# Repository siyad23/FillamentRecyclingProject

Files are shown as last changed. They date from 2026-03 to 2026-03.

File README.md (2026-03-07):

# Filament Recycling Project

A complete open-source plastic bottle-to-3D-printer-filament recycling machine, encompassing mechanical design, electrical design, and embedded firmware. The system heats, extrudes, and spools recycled plastic into usable 3D printing filament using a custom-built machine controlled by an ESP32-C6 microcontroller.

---

## Gallery

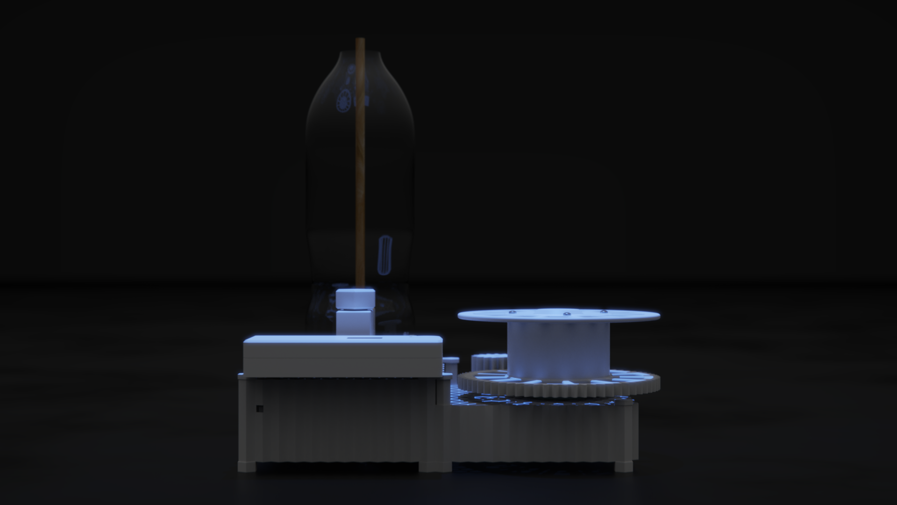
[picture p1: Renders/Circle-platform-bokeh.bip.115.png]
Render 1

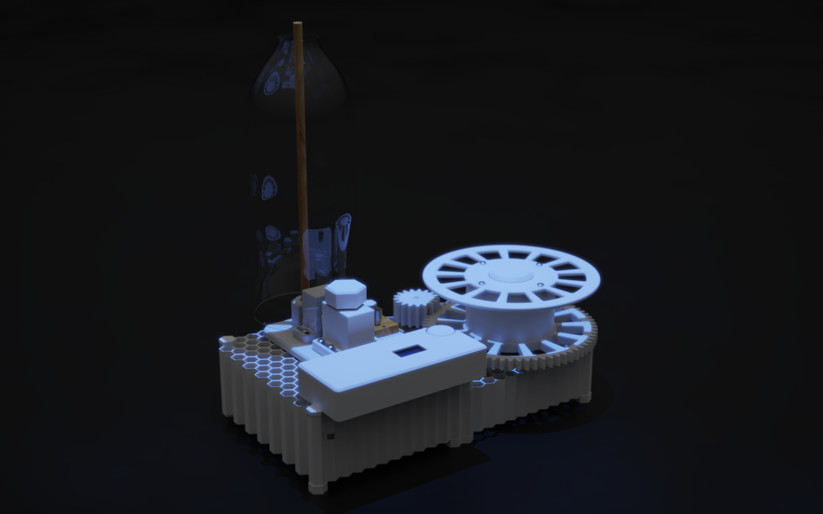
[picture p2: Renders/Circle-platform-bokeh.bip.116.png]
Render 2

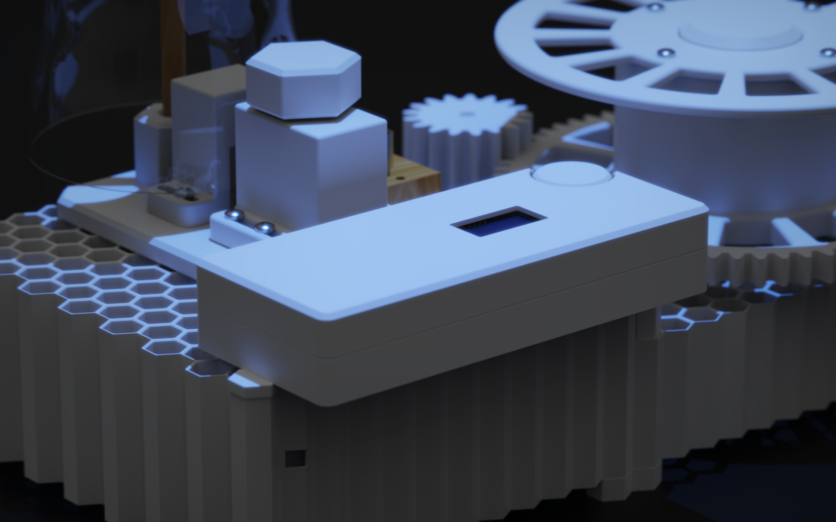
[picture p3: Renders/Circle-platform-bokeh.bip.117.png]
Render 3

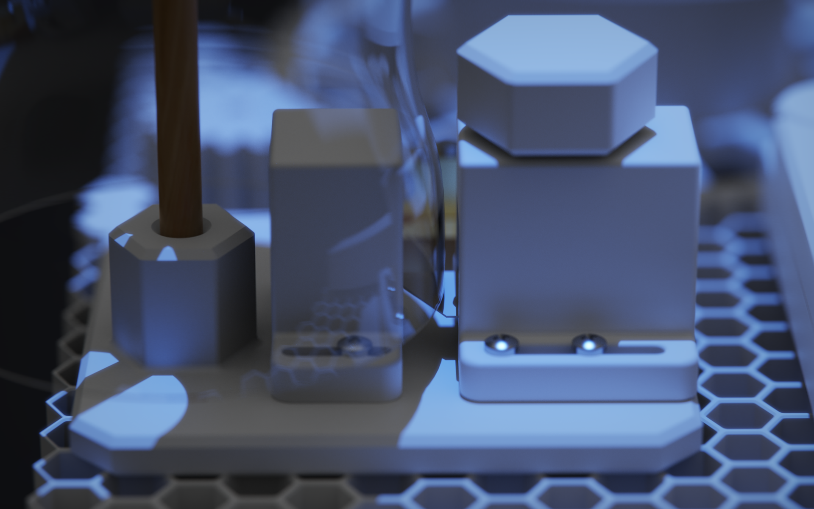
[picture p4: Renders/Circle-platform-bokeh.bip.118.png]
Render 4

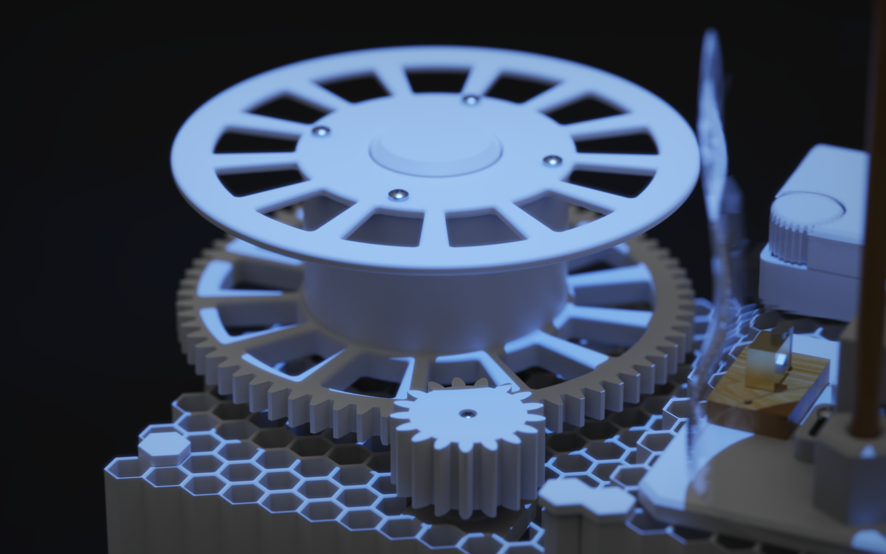
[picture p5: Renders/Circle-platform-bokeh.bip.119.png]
Render 5

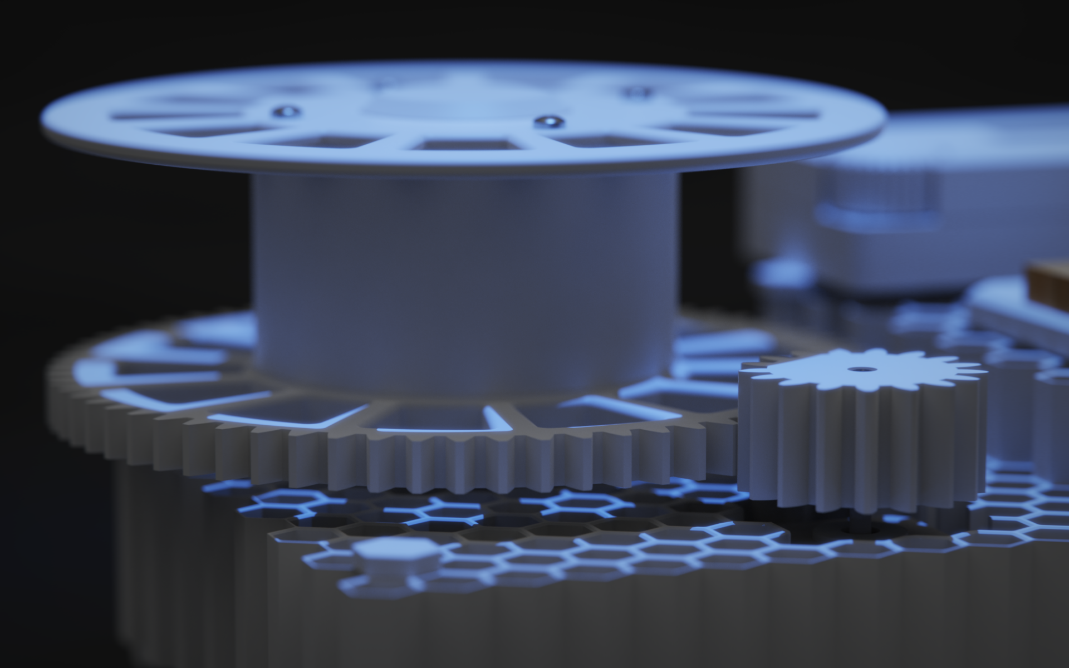
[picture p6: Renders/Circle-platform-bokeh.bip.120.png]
Render 6

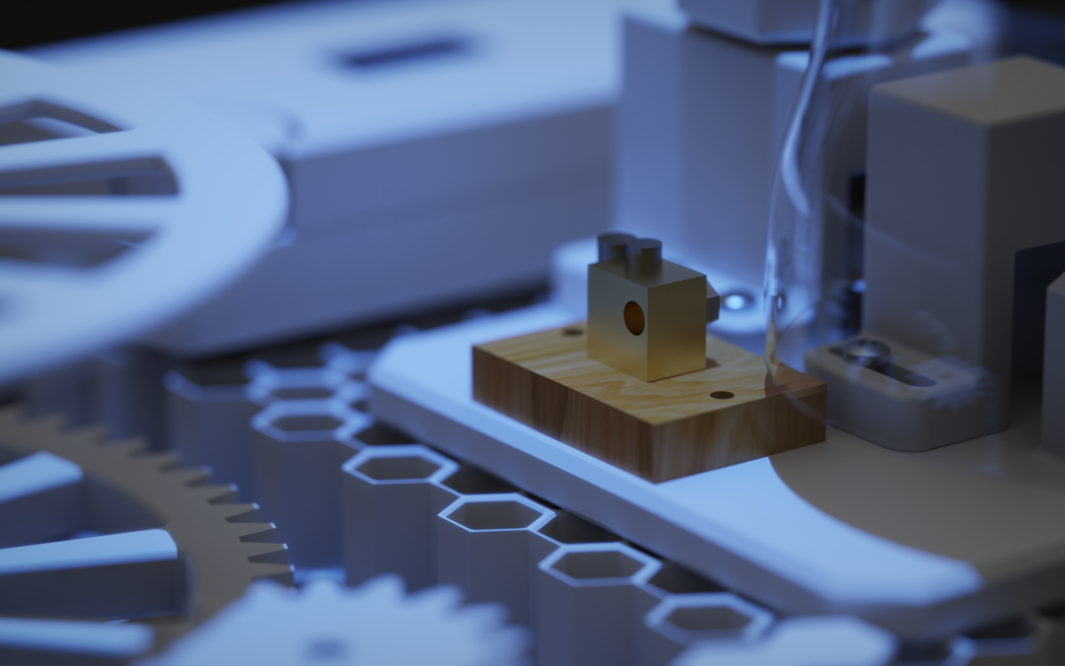
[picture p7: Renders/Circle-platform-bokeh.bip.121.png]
Render 7


---

## Table of Contents

- [Overview](#overview)
- [Features](#features)
- [Project Structure](#project-structure)
- [Hardware Components](#hardware-components)
- [Firmware](#firmware)
  - [Menu System](#menu-system)
  - [Pin Configuration](#pin-configuration)
  - [PID Temperature Control](#pid-temperature-control)
- [Mechanical Design](#mechanical-design)
  - [Cutting Mechanism](#cutting-mechanism)
  - [Gear Train](#gear-train)
  - [Spool Assembly](#spool-assembly)
  - [Electrical Enclosure](#electrical-enclosure)
  - [Production Phases](#production-phases)
- [Build & Flash](#build--flash)
- [Usage](#usage)
- [License](#license)

---

## Overview

This project converts plastic bottles into 3D printer filament through a process of cutting, heating, extruding, and spooling. The machine is driven by a stepper motor controlled through a TB6600 driver, with a heated extruder regulated by a PID controller reading a MAX6675 thermocouple. All user interaction is handled through a rotary encoder and a 128×64 SH1106 OLED display.

## Features

- **PID-controlled heated extruder** with closed-loop (PID) and open-loop (fixed power) modes
- **Stepper motor control** with configurable speed (0–100%) and microstepping (1, 2, 4, 8, 16, 32)
- **MAX6675 thermocouple** for real-time temperature monitoring (up to 250 °C)
- **128×64 SH1106 OLED display** with animated splash screen, scrollable menus, progress bars, and icons
- **Rotary encoder navigation** with acceleration-aware input for fast/slow value adjustment
- **Non-Volatile Storage (NVS)** — all settings (temperature, speed, PID gains, pin assignments) persist across power cycles with flash-wear-optimized writes
- **Fully configurable GPIO pins** — reassign stepper, heater, and thermocouple pins from the on-device menu
- **Time-proportional heater control** (1 Hz software PWM) for proportional power output without hardware PWM
- **4-phase 3D-printable mechanical design** with full SolidWorks source files

---

## Project Structure

```
fillamentRecyclingProject/
├── README.md
├── ElectricalDesign/                  # Electrical schematics & PCB designs
├── fillamentRecyclingProjectCode/     # ESP32-C6 firmware (ESP-IDF + PlatformIO)
│   ├── CMakeLists.txt
│   ├── platformio.ini                 # PlatformIO config (ESP32-C6-DevKitM-1)
│   ├── sdkconfig.esp32-c6-devkitm-1
│   ├── include/
│   ├── lib/
│   ├── src/
│   │   ├── main.c                     # Application entry point, menu system, control loop
│   │   ├── sh1106.c / sh1106.h        # SH1106 OLED display driver (I2C)
│   │   └── AiEsp32RotaryEncoder.c/.h  # Rotary encoder driver (ESP-IDF port)
│   └── test/
└── MechanicalDesign/                  # SolidWorks CAD files
    ├── MainAssembly.SLDASM            # Top-level assembly
    ├── baseAssembly.SLDASM            # Base frame assembly
    ├── spoolAssembly.SLDASM           # Spool winding assembly
    ├── electricalBoxAssembly.SLDASM   # Electronics enclosure assembly
    ├── CuttingMechanism/              # Bottle cutting sub-assembly
    ├── ProductionDocuments/           # 3D-print-ready STLs & build guides (Phase 1–4)
    └── ReferenceFiles/                # Vendor CAD models & datasheets
```

---

## Hardware Components

| Component | Description |
|---|---|
| **ESP32-C6-DevKitM-1** | Main microcontroller (RISC-V, Wi-Fi 6, BLE 5) |
| **SH1106 128×64 OLED** | I2C display (address 0x3C) for user interface |
| **HW-040 Rotary Encoder** | Navigation input with push-button |
| **TB6600 Stepper Driver** | Drives the extruder/spool stepper motor |
| **MAX6675 + K-Type Thermocouple** | Temperature sensing for the hotend (bit-banged SPI) |
| **Heater Cartridge** | Hotend heating element (time-proportional control) |
| **SMPS Power Supply** | Main power source |
| **BTS7960 Motor Driver** | Reference motor driver (in reference files) |
| **Bearings** | SKF 6008 (25×47×16 mm) and 63005-2RS1 |
| **Flexible Coupling (5×5 mm)** | Motor-to-shaft coupler |
| **Spur Gears** | 15T, 17T, and 67T gear train for speed reduction |

---

## Firmware

The firmware is written in **C** using the **ESP-IDF** framework and managed via **PlatformIO**.

### Menu System

The OLED display presents a hierarchical menu navigated entirely via the rotary encoder:

```
SPLASH (animated loading screen, 2 seconds)
└── MAIN MENU
    ├── Start/View Process  → RUN screen (live temp, motor speed, elapsed time, progress bar)
    │                         └── Confirm Stop dialog
    ├── Temperature         → Slider (30–250 °C, speed-adaptive steps: 1/5/10/20)
    ├── Motor Speed         → Slider (0–100%)
    ├── Microstep           → Selector (1/1, 1/2, 1/4, 1/8, 1/16, 1/32)
    ├── Hotend Mode         → Closed Loop (PID) / Open Loop (fixed %)
    │   └── Heater Power    → Slider (0–100%, open-loop only)
    ├── PID Settings
    │   ├── Kp (0.0–10.0)
    │   ├── Ki (0.0–5.0)
    │   └── Kd (0.0–10.0)
    └── Pin Settings        → Reassign all 7 GPIO pins (0–21)
```

### Pin Configuration

Default GPIO assignments (all configurable via the on-device menu):

| Function | Default GPIO |
|---|---|
| I2C SCL | 20 |
| I2C SDA | 19 |
| Encoder A | 15 |
| Encoder B | 18 |
| Encoder Button | 14 |
| Stepper STEP | 4 |
| Stepper DIR | 5 |
| Stepper ENABLE | 6 |
| Heater | 7 |
| MAX6675 CLK | 10 |
| MAX6675 CS | 11 |
| MAX6675 DO | 12 |

### PID Temperature Control

The closed-loop temperature controller implements:

- **Proportional, Integral, Derivative** control with configurable gains
- **Derivative-on-measurement** (avoids setpoint kick on temperature changes)
- **Anti-windup** clamping on the integral term (±100)
- **Time-proportional output** — a 1-second window where the heater is on for `(pid_output / 100) × 1000 ms`
- Temperature sampled every 250 ms from the MAX6675 (respecting the sensor's ~220 ms conversion time)

---

## Mechanical Design

All CAD files are in **SolidWorks** format (.SLDPRT for parts, .SLDASM for assemblies).

### Cutting Mechanism

Located in `MechanicalDesign/CuttingMechanism/`:

- **Blade & Blade Holder** — upper and lower holders secure the cutting blade
- **Blade Housing** — enclosed cutting chamber
- **Bottle Base & Size Adjustor** — accommodates different bottle diameters
- **Height Adjustment Screws** — fine-tune blade position
- **Metal Rod** — structural support for the cutting assembly

### Gear Train

Three spur gears provide mechanical advantage for the extrusion process:

- **15T Spur Gear** — driver gear
- **17T Spur Gear** — intermediate gear
- **67T Spur Gear** — driven gear (high torque output)

### Spool Assembly

- **Filament Spool** (2 variants) — collects the finished filament
- **Spool Plate** — mounting plate for the spool
- **Coupler** — connects motor shaft to spool mechanism
- **Knob** — manual spool adjustment

### Electrical Enclosure

- **Electrical Box** + **Lid** — houses the ESP32, motor driver, and power supply
- **Mount Stand** — secures the enclosure to the base

### Base Frame

- **Base** (standard and hex variants) — machine foundation
- **Base Feet & Double Joiner Feet** — anti-vibration feet
- **Base Joiner** — connects base sections
- **Bearing Mount** — supports rotating shafts (SKF 6008 / 63005-2RS1)
- **Fasteners** (1× and 4× variants) — structural fasteners

### Production Phases

The build is organized into 4 print phases under `MechanicalDesign/ProductionDocuments/`:

| Phase | Parts (STL files) | Description |
|---|---|---|
| **Phase 1** | Base, Blade Holder, Blade Housing, Height Adjustment Screws, Size Adjustor | Cutting mechanism & base plate |
| **Phase 2** | Base (×3), Base Feet (×2), Base Joiner, Double Joiner Feet, Fasteners (×2) | Frame structure & assembly |
| **Phase 3** | Bearing Mount, Electrical Box & Lid, Fasteners, Knob, Mount Stand, Spool, Spool Plate, Spur Gear | Enclosure, spool, and drive train |
| **Phase 4** | Blade Holder, Spur Gear | Final assembly parts |

Each phase includes a PDF/DOCX build guide.

---

## Build & Flash

### Prerequisites

- [PlatformIO](https://platformio.org/) (VS Code extension or CLI)
- ESP32-C6-DevKitM-1 board
- USB-C cable

### Steps

```bash
# Clone the repository
git clone <repository-url>
cd fillamentRecyclingProject/fillamentRecyclingProjectCode

# Build the firmware
pio run -e esp32-c6-devkitm-1

# Flash to the board
pio run -e esp32-c6-devkitm-1 --target upload

# Monitor serial output
pio device monitor
```

---

## Usage

1. **Power on** — the OLED displays an animated splash screen with a recycling logo.
2. **Navigate** — rotate the encoder to scroll through menu items; click to select.
3. **Configure** — set temperature (30–250 °C), motor speed, microstepping, hotend mode, and PID gains.
4. **Start** — select "Start Process" to enable the heater and motor. The run screen shows live temperature, target, heater power %, motor speed, elapsed time, and a temperature progress bar.
5. **Stop** — select "STOP" on the run screen or long-press the encoder (1 second) from the main menu. A confirmation dialog prevents accidental shutdowns.
6. **Settings persist** — all parameters are saved to flash automatically and restored on next boot.

---

## License

This project is licensed under the MIT License - see the [LICENSE](LICENSE) file for details.

Copyright (c) 2026 Rahat Khan Siyad

The rotary encoder library is based on [ai-esp32-rotary-encoder](https://github.com/igorantolic/ai-esp32-rotary-encoder) by Igor Antolic (MIT License).

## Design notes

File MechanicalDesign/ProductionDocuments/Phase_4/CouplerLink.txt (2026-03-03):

https://store.roboticsbd.com/robotics-parts/2260-5mm-motor-shaft-coupling-brass-hex-18mm-length-robotics-bangladesh.html

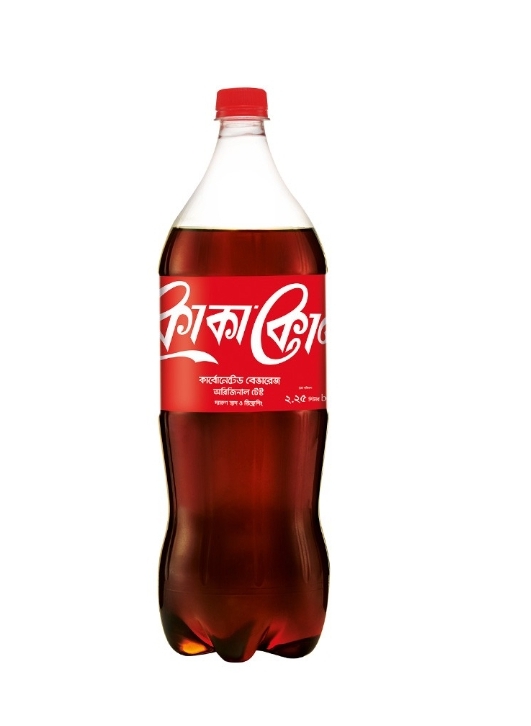
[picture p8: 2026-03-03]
MechanicalDesign/ReferenceFiles/YGOv7M2TLwKPeQucEshsfxZYIpocbmotxgK6eAaB.jpg

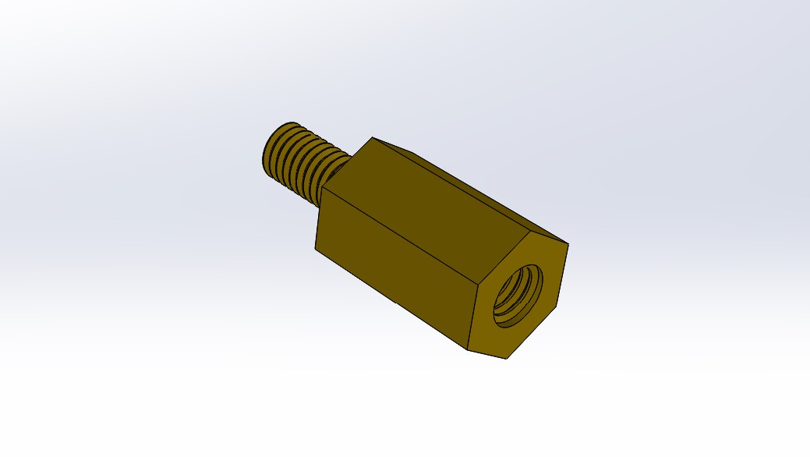
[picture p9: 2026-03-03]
MechanicalDesign/ReferenceFiles/m3-x10mm-spacer-1.snapshot.1/Spacer .jpg

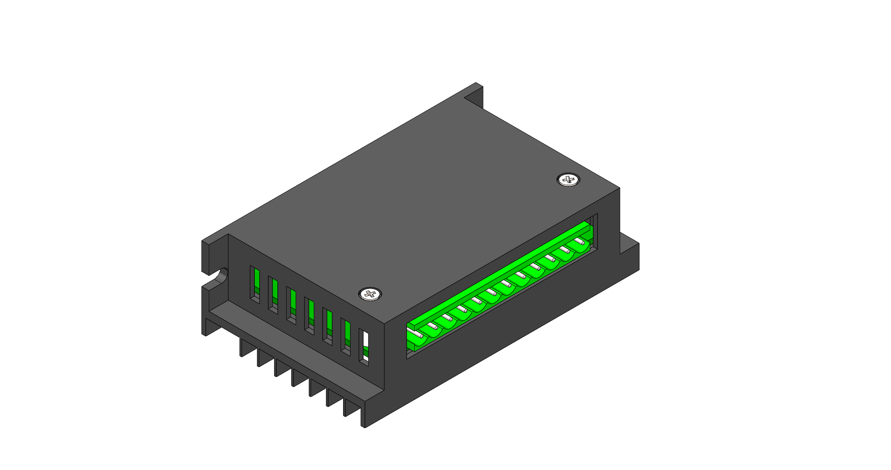
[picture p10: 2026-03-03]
MechanicalDesign/ReferenceFiles/TB6600_MotorDriver/MotordriverAssebly.PNG

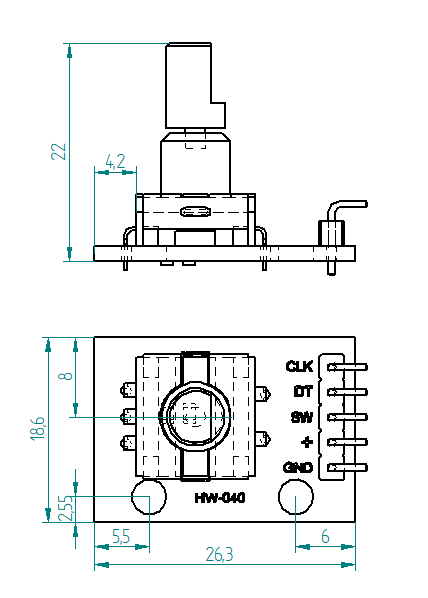
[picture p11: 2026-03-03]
MechanicalDesign/ReferenceFiles/hw-040-rotary-encoder-for-arduino-1.snapshot.3/HW-040 Module dimensions.png

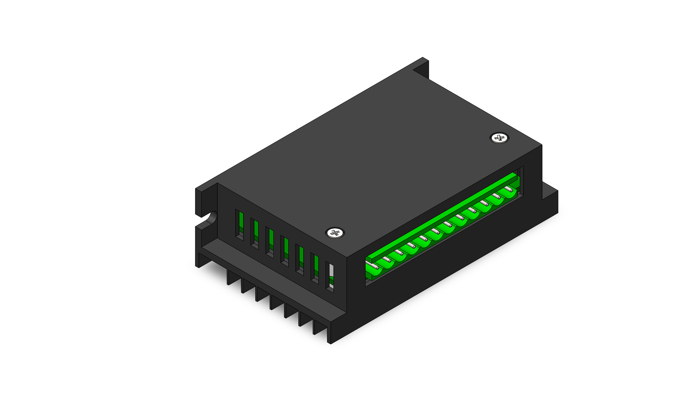
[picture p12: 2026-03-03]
MechanicalDesign/ReferenceFiles/TB6600_MotorDriver/Assem1.JPG

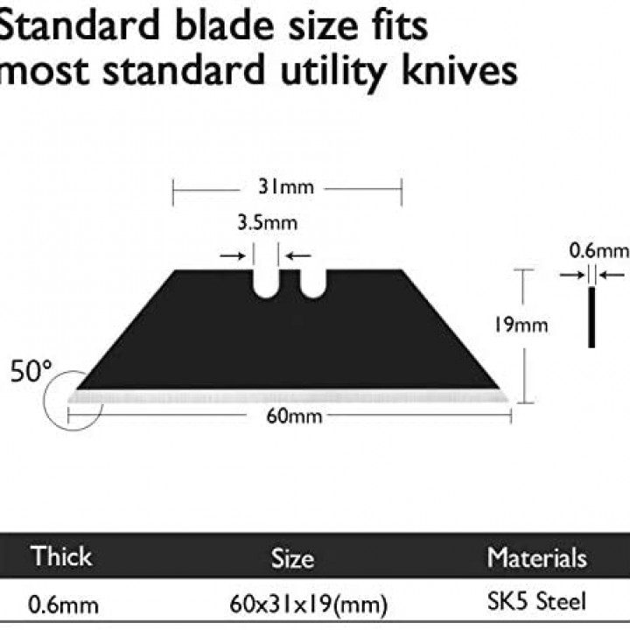
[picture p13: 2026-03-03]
MechanicalDesign/ReferenceFiles/bladeDimensions.jpg

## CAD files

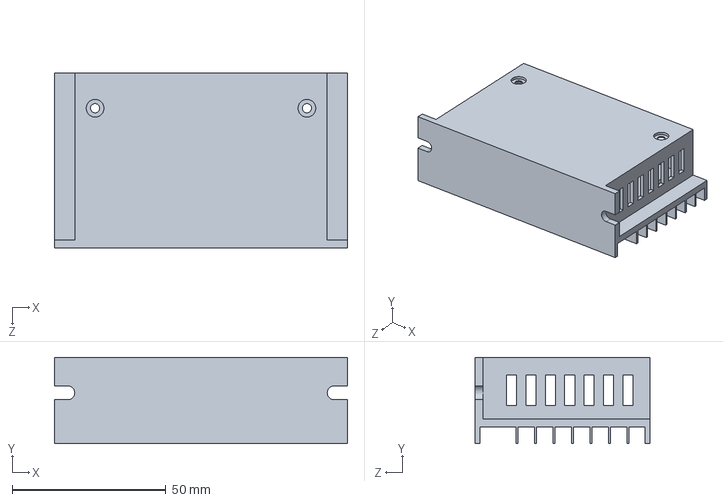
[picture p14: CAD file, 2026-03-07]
MechanicalDesign/ReferenceFiles/TB6600_MotorDriver/mainBody.SLDPRT
95.3 x 28.1 x 56.8 mm

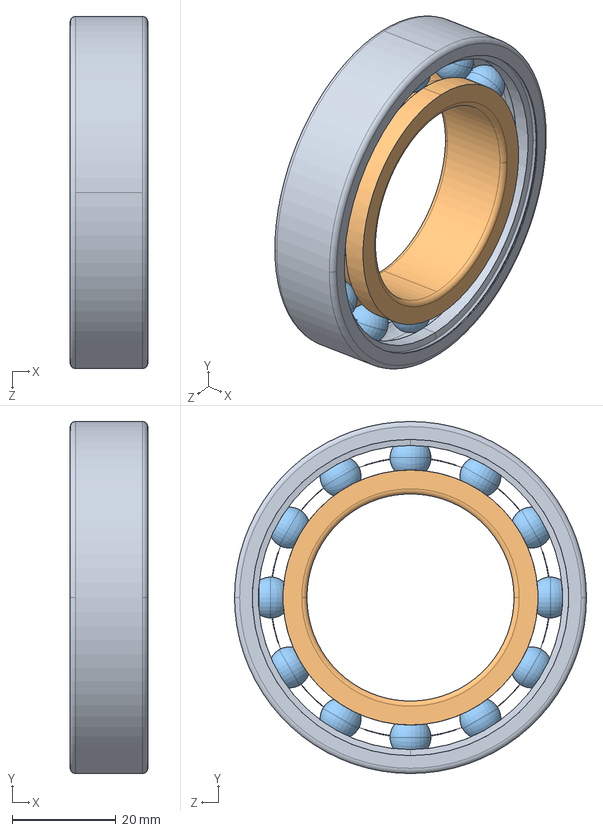
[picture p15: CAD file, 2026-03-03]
MechanicalDesign/ReferenceFiles/175567098-7-6008/6008.SLDASM
15.0 x 68.0 x 68.0 mm

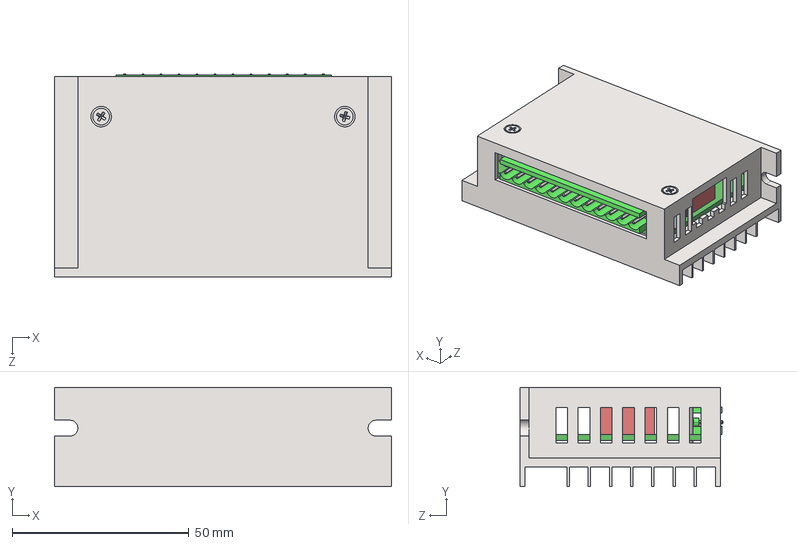
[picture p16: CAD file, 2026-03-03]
MechanicalDesign/ReferenceFiles/TB6600_MotorDriver/Assembly.STEP
95.3 x 28.1 x 57.5 mm
PCB
MaleConnector
switch
mainBody
bottomSpacer x 2
topSpacer x 2
flat head screw_am_B18.6.7M - M2.5 x 0.45 x 20 Type I Cross Recessed FHMS --20C x 2

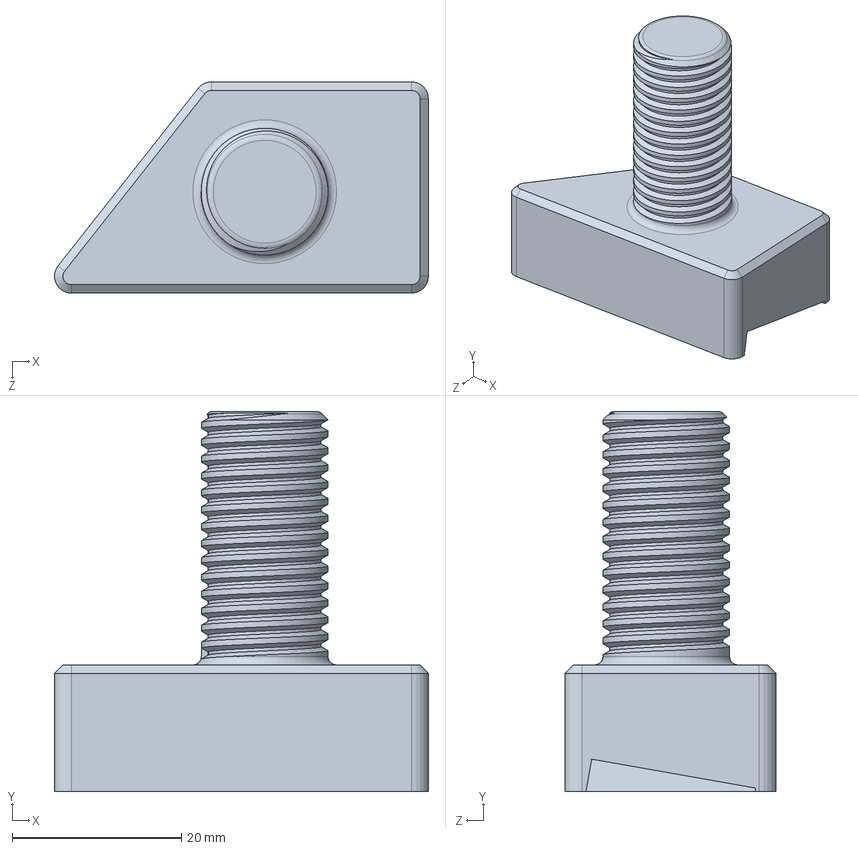
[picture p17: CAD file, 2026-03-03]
MechanicalDesign/CuttingMechanism/bladeHolder.SLDPRT
44.2 x 45.0 x 25.0 mm

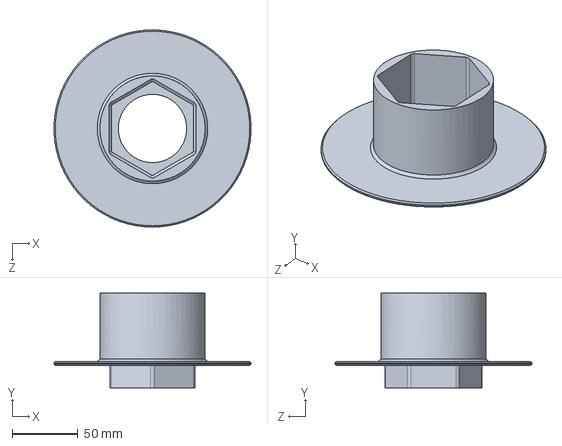
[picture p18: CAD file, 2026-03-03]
MechanicalDesign/fillametSpool2.SLDPRT
149.9 x 72.0 x 150.0 mm

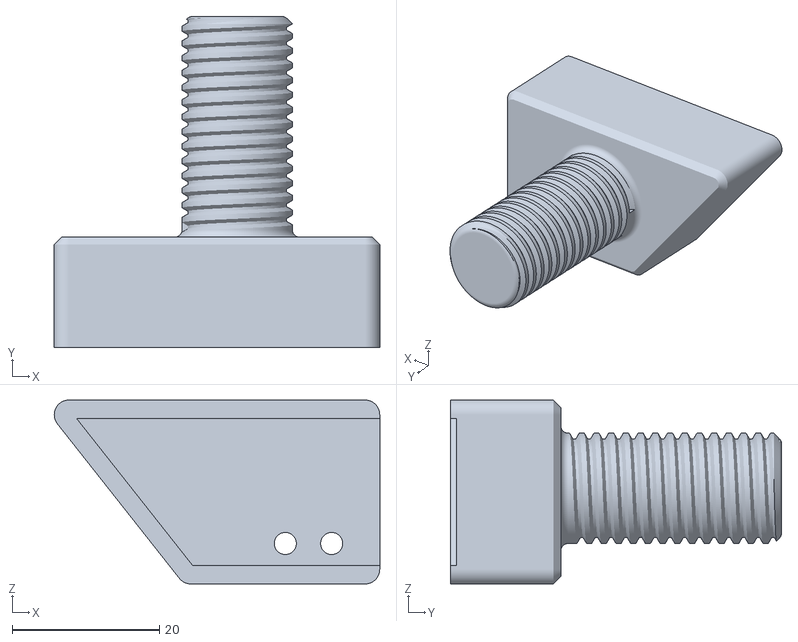
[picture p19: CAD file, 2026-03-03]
MechanicalDesign/ProductionDocuments/Phase_1/bladeHolder.STL
44.3 x 45.0 x 25.0

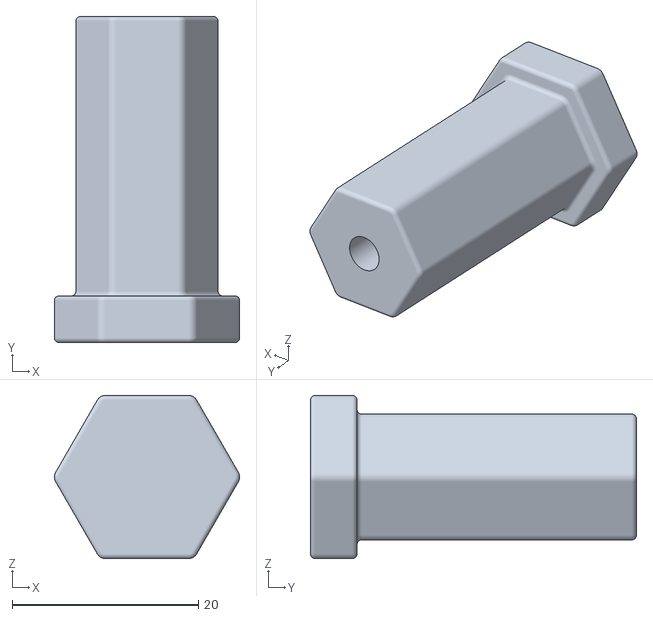
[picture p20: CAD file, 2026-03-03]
MechanicalDesign/ProductionDocuments/Phase_2/baseFeet_2.STL
19.9 x 35.0 x 17.5

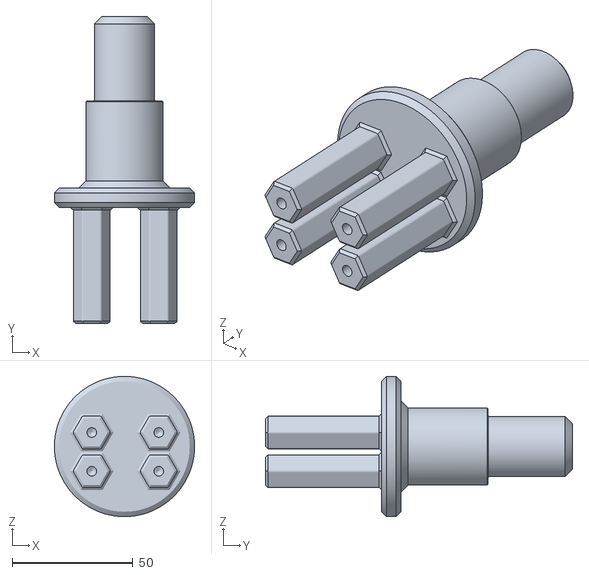
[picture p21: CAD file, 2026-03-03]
MechanicalDesign/ProductionDocuments/Phase_3/mountStand.STL
58.0 x 127.0 x 58.0

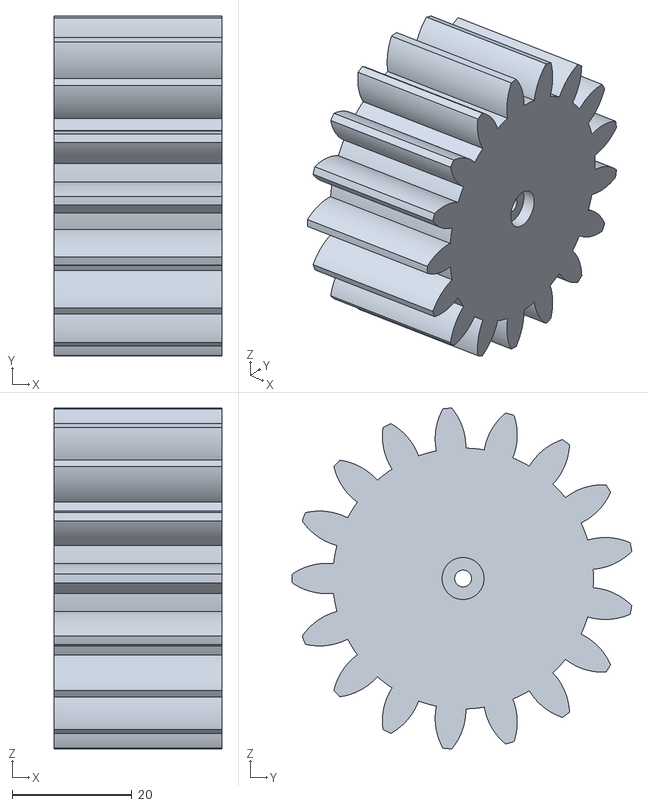
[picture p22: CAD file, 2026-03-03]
MechanicalDesign/ProductionDocuments/Phase_4/SpurGear.STL
28.0 x 56.6 x 56.9

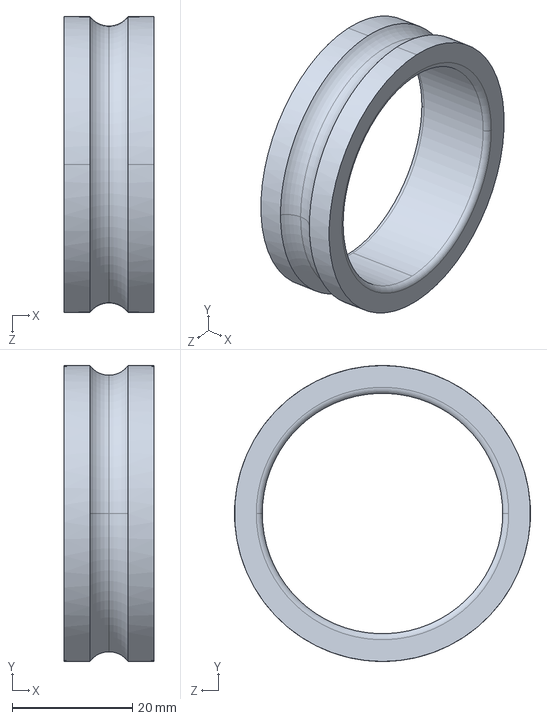
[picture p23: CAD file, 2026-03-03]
MechanicalDesign/ReferenceFiles/175567098-7-6008/6008_02.SLDPRT
15.0 x 49.2 x 49.2 mm

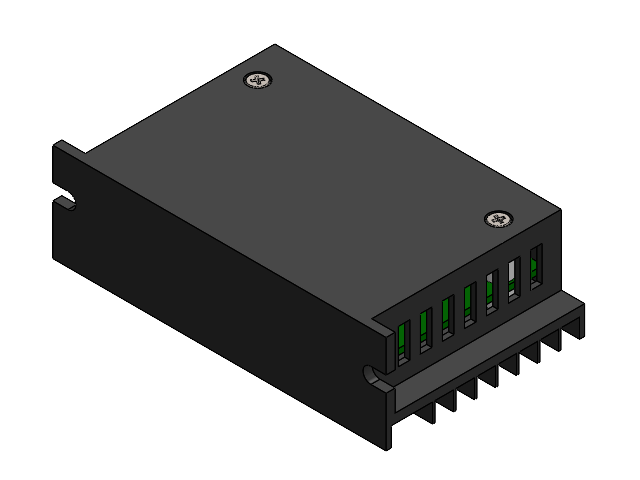
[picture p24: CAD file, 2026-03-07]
MechanicalDesign/ReferenceFiles/TB6600_MotorDriver/MotordriverAssebly.SLDASM
PCB
MaleConnector
switch
mainBody
bottomSpacer x 2
topSpacer x 2
flat head screw_am x 2

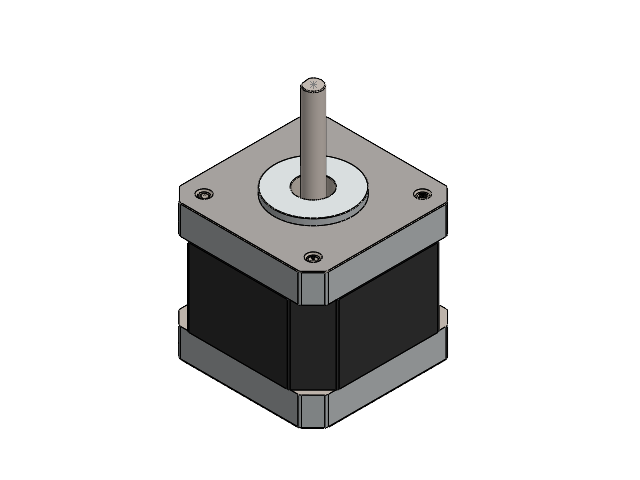
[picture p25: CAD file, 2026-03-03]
MechanicalDesign/ReferenceFiles/MotorDesign/motorAssembly.SLDASM
bottomPlate
midBody
shaft
topPlate
jstConnector

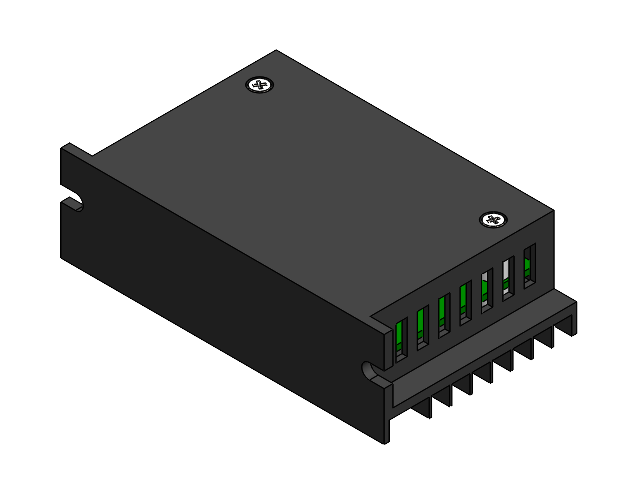
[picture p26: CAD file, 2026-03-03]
MechanicalDesign/ReferenceFiles/TB6600_MotorDriver/Assem1.SLDASM
PCB
MaleConnector
switch
mainBody
bottomSpacer x 2
topSpacer x 2
flat head screw_am x 2

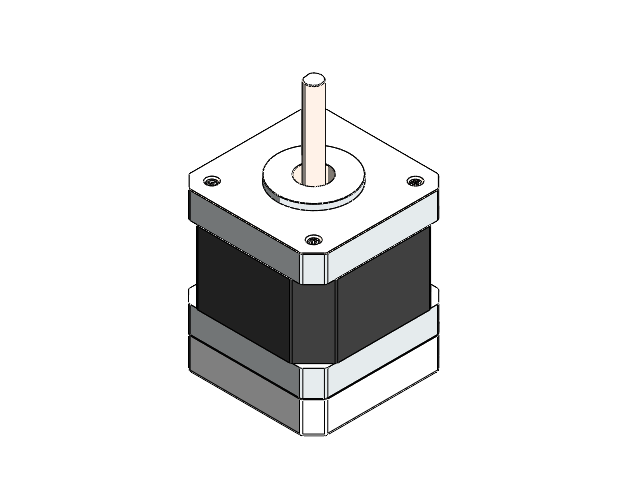
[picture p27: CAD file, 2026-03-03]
MechanicalDesign/ReferenceFiles/MotorDesign/motorWithEncoder.SLDASM
bottomPlate
midBody
shaft
topPlate
jstConnector
magneticEncoderEnclosure
AS5600

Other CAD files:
MechanicalDesign/spoolAssembly.SLDASM
MechanicalDesign/ReferenceFiles/TB6600_MotorDriver/MotordriverAsseblys.SLDASM
MechanicalDesign/ReferenceFiles/TB6600_MotorDriver/mainBodys.SLDPRT
MechanicalDesign/electricalBoxAssembly.SLDASM
MechanicalDesign/15xSpurGear.SLDPRT
MechanicalDesign/17xSpurGear.SLDPRT
MechanicalDesign/67xSpurGear.SLDPRT
MechanicalDesign/Base.SLDPRT
MechanicalDesign/Coupler.SLDPRT
MechanicalDesign/CuttingMechanism/Part3.SLDPRT
MechanicalDesign/CuttingMechanism/blade.SLDPRT
MechanicalDesign/CuttingMechanism/bladeHolder_Lower.SLDPRT
MechanicalDesign/CuttingMechanism/bladeHousing.SLDPRT
MechanicalDesign/CuttingMechanism/bottle.SLDPRT
MechanicalDesign/CuttingMechanism/bottleBase.SLDPRT
MechanicalDesign/CuttingMechanism/bottleSizeAdjustor.SLDPRT
MechanicalDesign/CuttingMechanism/heightAdjustmentScrews.SLDPRT
MechanicalDesign/CuttingMechanism/metalRod.SLDPRT
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

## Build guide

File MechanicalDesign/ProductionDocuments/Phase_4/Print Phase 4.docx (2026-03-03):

# Print Phase – 4

All files are in this drive folder: Phase_4_Files (https://drive.google.com/drive/folders/1dxNh4X9nQZPrIZS_Qf4CVorg8Dkla8L0?usp=sharing)

***The print orientation is shown in pictures. If the parts fail to print in that orientation, you may change the orientation.

# 1. Base Type 1

file Name: bladeHolder.STL

Link: bladeHolder (https://drive.google.com/file/d/19umH6-jGS0w7vAI4DKsR5vvIBFBa8NWH/view?usp=drive_link)

Infill: 20%.

Wall Loops: 5

Color: White

Precision (Flowrate): High (Low)

Material: PETG

Quantity: 1

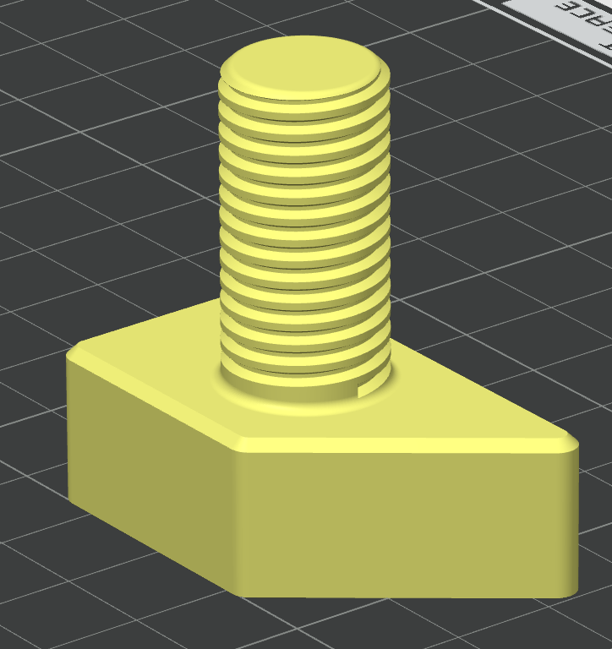
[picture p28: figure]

# 2. Base Type 2

file Name: spurGear.STL

Link: SpurGear (https://drive.google.com/file/d/1pW3XLnhzH5lOOCwImbOTlCXtp-f2U9rn/view?usp=drive_link)

Infill: 20%.

Wall Loops: 6

Color: White

Precision (Flowrate): High (Low)

Material: PETG

Quantity: 1

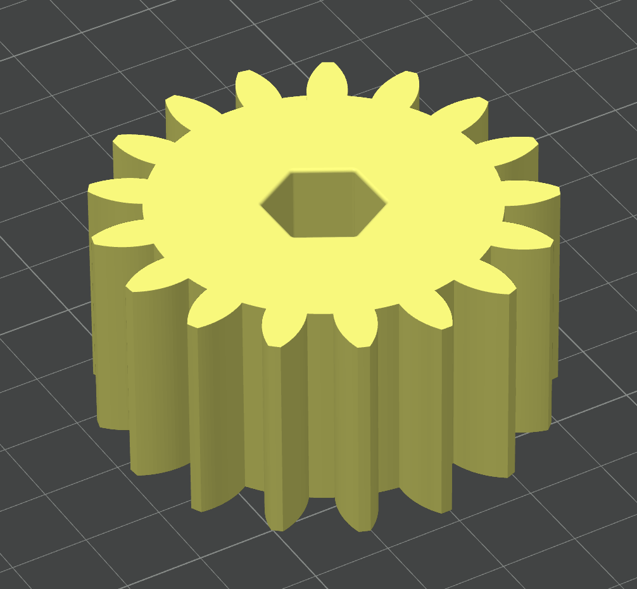
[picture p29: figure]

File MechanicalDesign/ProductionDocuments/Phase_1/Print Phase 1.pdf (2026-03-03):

## Print Phase – 1

All files are in this drive folder: Phase_1_Files (https://drive.google.com/drive/folders/1WSvoMfZPsJ0MehgL9uLIRmyDcuyFN0G7?usp=sharing)
***The print orientation is shown in pictures. If the parts fail to print in that orientation, you may change the orientation.

## 1. Base

file Name: Base.STL
Link: base.stl (https://drive.google.com/file/d/1UHYACKnU-G3ZPhq-Jozfw69xOXjVucC-/view?usp=drive_link)
Infill: 20%
Color: White
Precision (Flowrate): Medium (Medium) Material: PETG
Quantity: 1

## 2. Size Adjustor

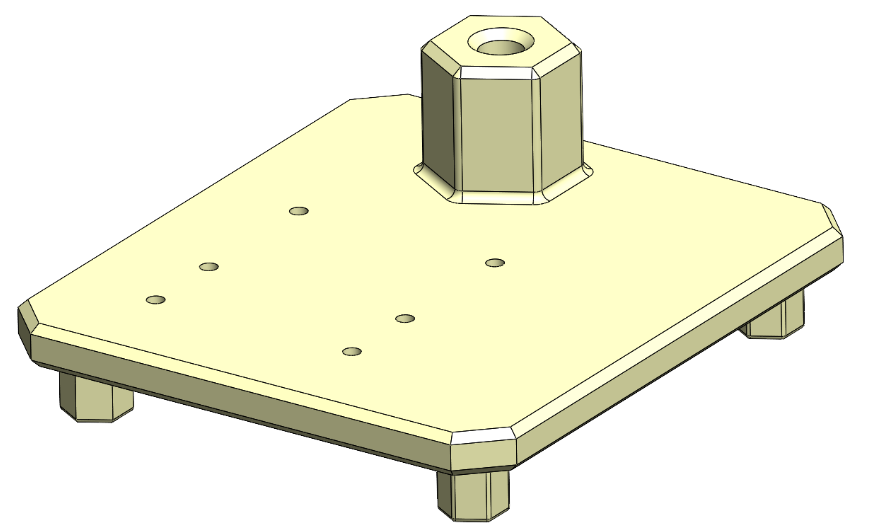
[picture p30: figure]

file Name: SizeAdjustor.STL Link: SizeAdjustor (https://drive.google.com/file/d/17B-TPPNcGwmfyJ7Izo8fIt5Hx-thai_7/view?usp=drive_link%20)
Infill: 20%
Color: White
Precision (Flowrate): Medium (Medium) Material: PETG
Quantity: 1

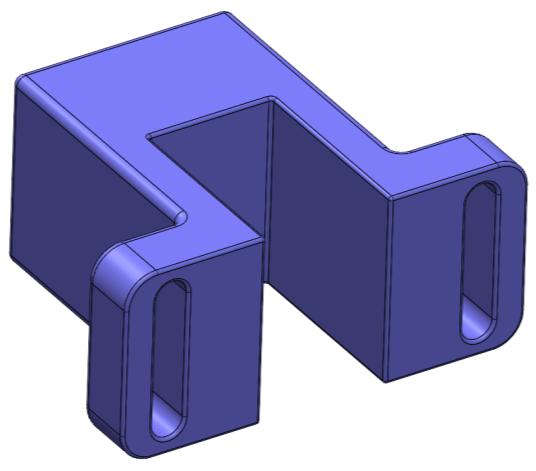
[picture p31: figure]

## 3. Blade Housing

file Name: bladeHousing.STL Link: bladeHousing (https://drive.google.com/file/d/1ppzdyYx5xnflyTPJfxlkGqCSifSpGc2D/view?usp=drive_link)
Infill: 50%
Color: White
Precision (Flowrate): High (Low) Material: PETG
Quantity: 1

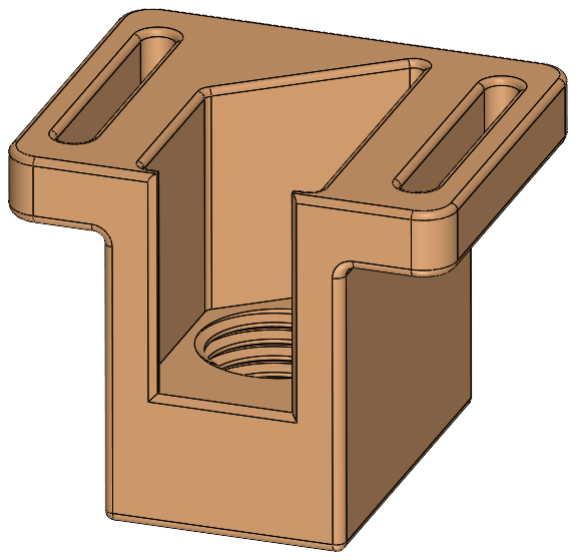
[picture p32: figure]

## 4. Height Adjustment Screws

file Name: heightAdjustmentScrews.STL Link: Height Adjustment Screw (https://drive.google.com/file/d/1_J2YKfBeCB6f8us9OgAvSePtq2RhFYCQ/view?usp=drive_link) Infill: 100%
Color: White
Precision (Flowrate): High (Low) Material: PETG
Quantity: 1

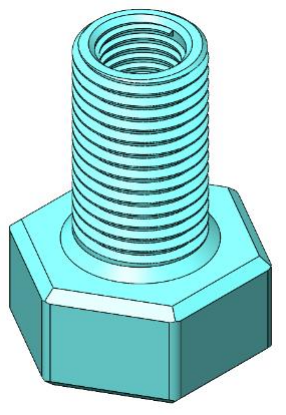
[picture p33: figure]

## 5. Blade Holder

file Name: bladeHolder.STL Link: Blade Holder (https://drive.google.com/file/d/1RLKKcdfgmAFinrsudui_7Hy15BGoWMDB/view?usp=drive_link)
Infill: 100%
Color: White
Precision (Flowrate): High (Low) Material: PETG
Quantity: 1

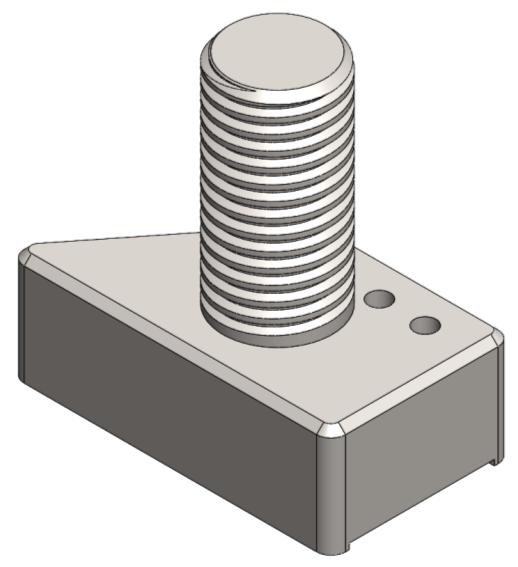
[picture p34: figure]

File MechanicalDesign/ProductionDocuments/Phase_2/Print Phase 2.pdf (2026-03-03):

## Print Phase – 2

All files are in this drive folder: Phase_2_Files (https://drive.google.com/drive/folders/1ckEbaZk5ueLycC-nyGt0o94hCsYbXyoY?usp=sharing)
***The print orientation is shown in pictures. If the parts fail to print in that orientation, you may change the orientation.

## 1. Base Type 1

file Name: base_1.STL
Link: base_1 (https://drive.google.com/file/d/1gZtpgf8GCtCvHxyPTHGil1UXmlYVr2SU/view?usp=drive_link)
Infill: Suitable.
Color: White
Precision (Flowrate): Low (Fast) Material: PETG
Quantity: 1

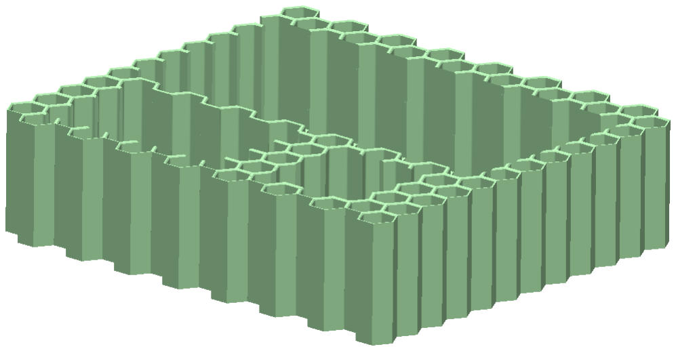
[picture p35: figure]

## 2. Base Type 2

file Name: base_2.STL
Link: base_2 (https://drive.google.com/file/d/1GWHi0oVEw0ubdA285V28ce4OOLxkwNcm/view?usp=drive_link)
Infill: Suitable.
Color: White
Precision (Flowrate): Low (Fast) Material: PETG
Quantity: 1

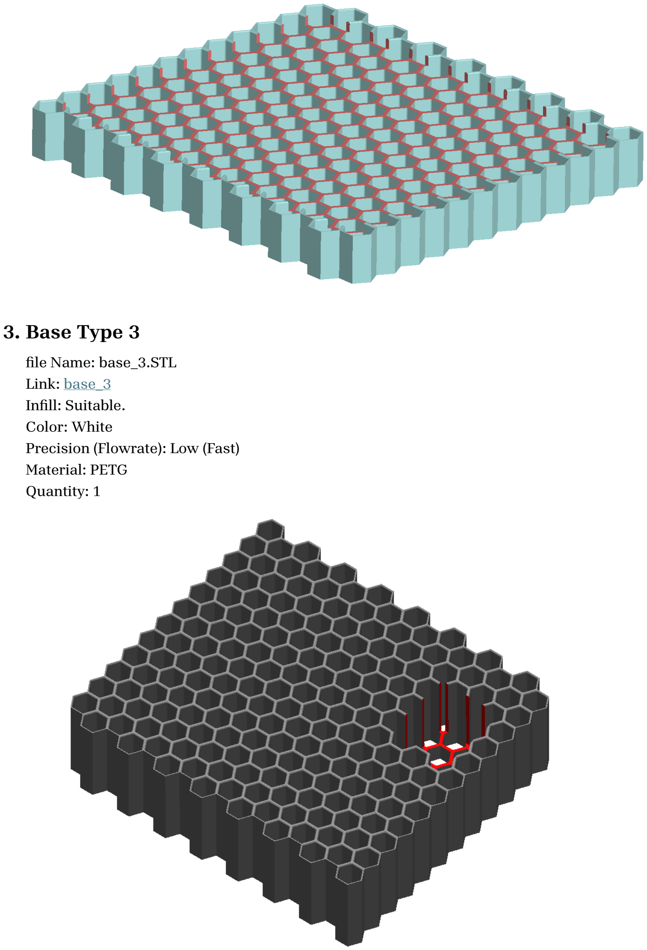
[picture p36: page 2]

## 3. Base Type 3

file Name: base_3.STL
Link: base_3 (https://drive.google.com/file/d/154PpvX5uqRgkBaNvnUK_x6Lj8FMNqOnB/view?usp=drive_link)
Infill: Suitable.
Color: White
Precision (Flowrate): Low (Fast) Material: PETG
Quantity: 1

## 4. Base Feet 1

file Name: baseFeet_1.STL
Link: baseFeet_1 (https://drive.google.com/file/d/15wR5eA5WmegZ7OubD0MNC_De1uuY8jKC/view?usp=drive_link)
Infill: 15%
Color: White
Precision (Flowrate): Medium (Medium) Material: PETG
Quantity: 2

## 5. Fastner 1

file Name: fastner_1.STL
Link: fastner_1 (https://drive.google.com/file/d/1apuuuK4CM5rZ0UlbHiXBvsUrqE-i4ywC/view?usp=drive_link)
Infill: 15%
Color: White

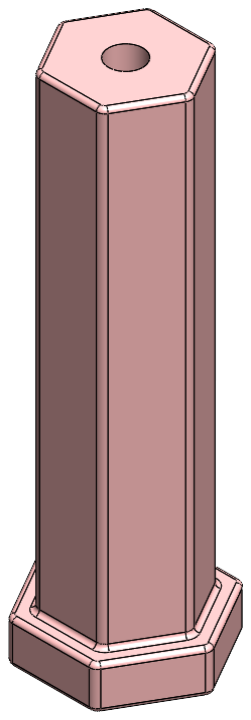
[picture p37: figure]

Precision (Flowrate): Medium (Medium) Material: PETG
Quantity: 4

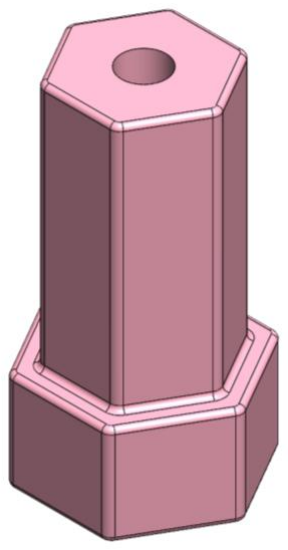
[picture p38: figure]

## 6. Base Feet 2

file Name: baseFeet_2.STL
Link: baseFeet_2 (https://drive.google.com/file/d/1KkTpOFTDezJNd2ygW-WRR9dz11CWE5gB/view?usp=drive_link)
Infill: 15%
Color: White
Precision (Flowrate): Medium (Medium) Material: PETG
Quantity: 2

## 7. Faster 2

file Name: fastner_2.STL
Link: fastner_2 (https://drive.google.com/file/d/113wZBstO2paS9thOvhAKlfUDvri4dNns/view?usp=drive_link)
Infill: 15%
Color: White

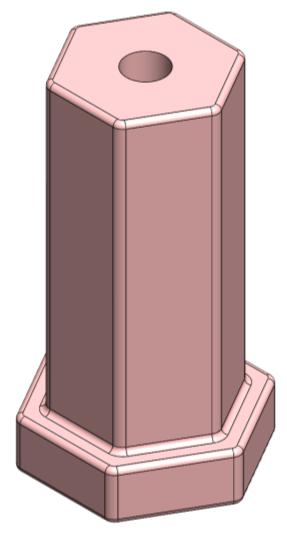
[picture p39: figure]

Precision (Flowrate): Medium (Medium) Material: PETG
Quantity: 4

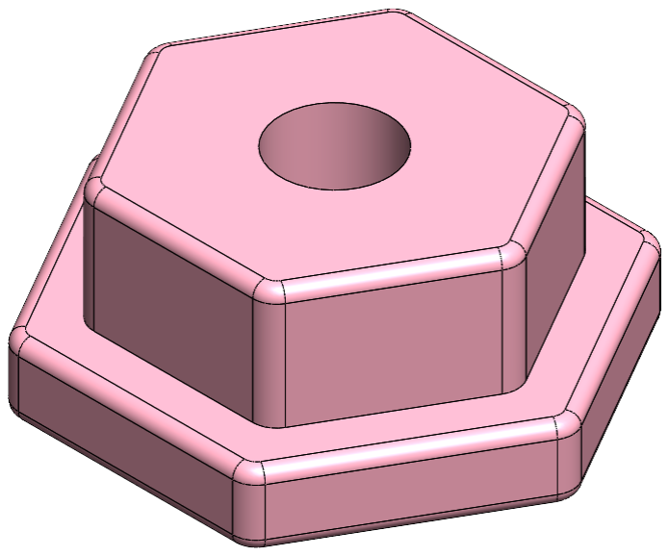
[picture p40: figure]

## 8. Double Joiner Feet

file Name: doubleJoinerFeet.STL Link: doubleJoinerFeet (https://drive.google.com/file/d/1zKG9xAqvF-LjPLgiZdxpNj-ba0aP1kJj/view?usp=drive_link)
Infill: 15%
Color: White
Precision (Flowrate): Medium (Medium) Material: PETG
Quantity: 2

## 9. Base Joiner

file Name: baseJoiner.STL
Link: baseJoiner (https://drive.google.com/file/d/1lm-Oztm4HNnPbTkQZDYVusAFCmCXS0df/view?usp=drive_link)
Infill: 15%
Color: White

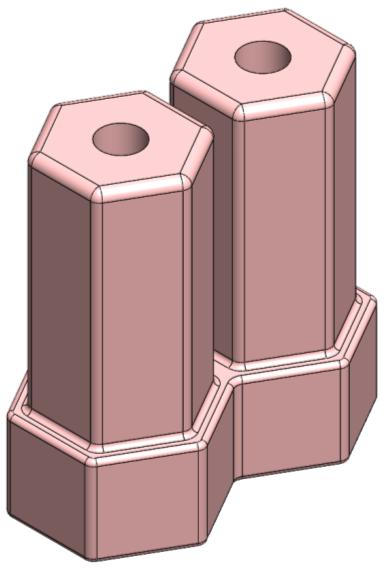
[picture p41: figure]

Precision (Flowrate): Medium (Medium) Material: PETG
Quantity: 2

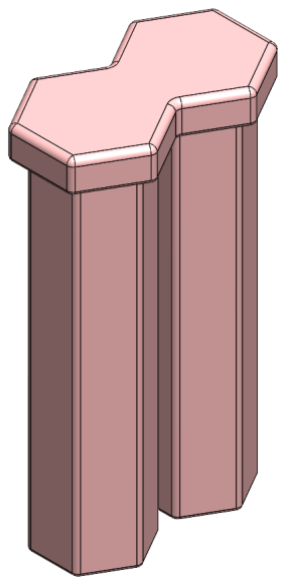
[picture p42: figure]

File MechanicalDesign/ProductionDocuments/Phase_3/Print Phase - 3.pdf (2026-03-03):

## Print Phase – 3

All files are in this drive folder: Phase_3_Files (https://drive.google.com/drive/folders/16H1goSZddqxEpI7scdXul8vFLeISQ0ar?usp=drive_link)
***The print orientation is shown in pictures. If the parts fail to print in that orientation, you may change the orientation.

## 1. Bearing Mount

file Name: bearingMount.STL Link: bearingMount (https://drive.google.com/file/d/1PegC0-CDQ_MpKeC28fvTZscEFJz3cIRa/view?usp=drive_link)
Infill: 18%
Color: White
Precision (Flowrate): Medium (Medium) Material: PETG
Quantity: 1

## 2. Fastner

file Name: fastner.STL
Link: fastner (https://drive.google.com/file/d/1JakagQe4OZ13YPoIaNcW0wmEl8V-7rms/view?usp=drive_link)
Infill: 18 %
Color: White
Precision (Flowrate): Low (Fast) Material: PETG
Quantity: 2

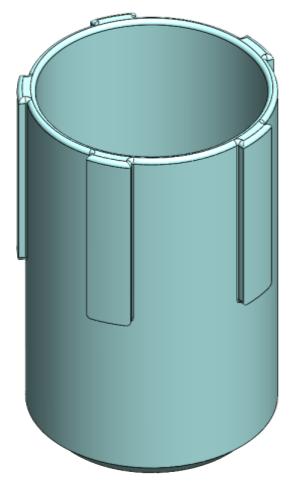
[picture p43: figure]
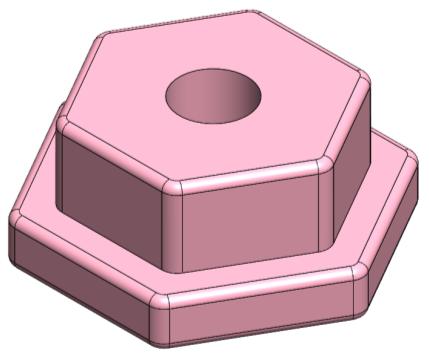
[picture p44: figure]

## 3. Electrical Box

file Name: electricalBox.STL Link: electricalBox (https://drive.google.com/file/d/11cPkGoU3Ul0NBxOPb6ZyPJbhJFt_GFsU/view?usp=drive_link)
Infill: 18%
Color: White
Precision (Flowrate): Low (Fast) Material: PETG
Quantity: 1

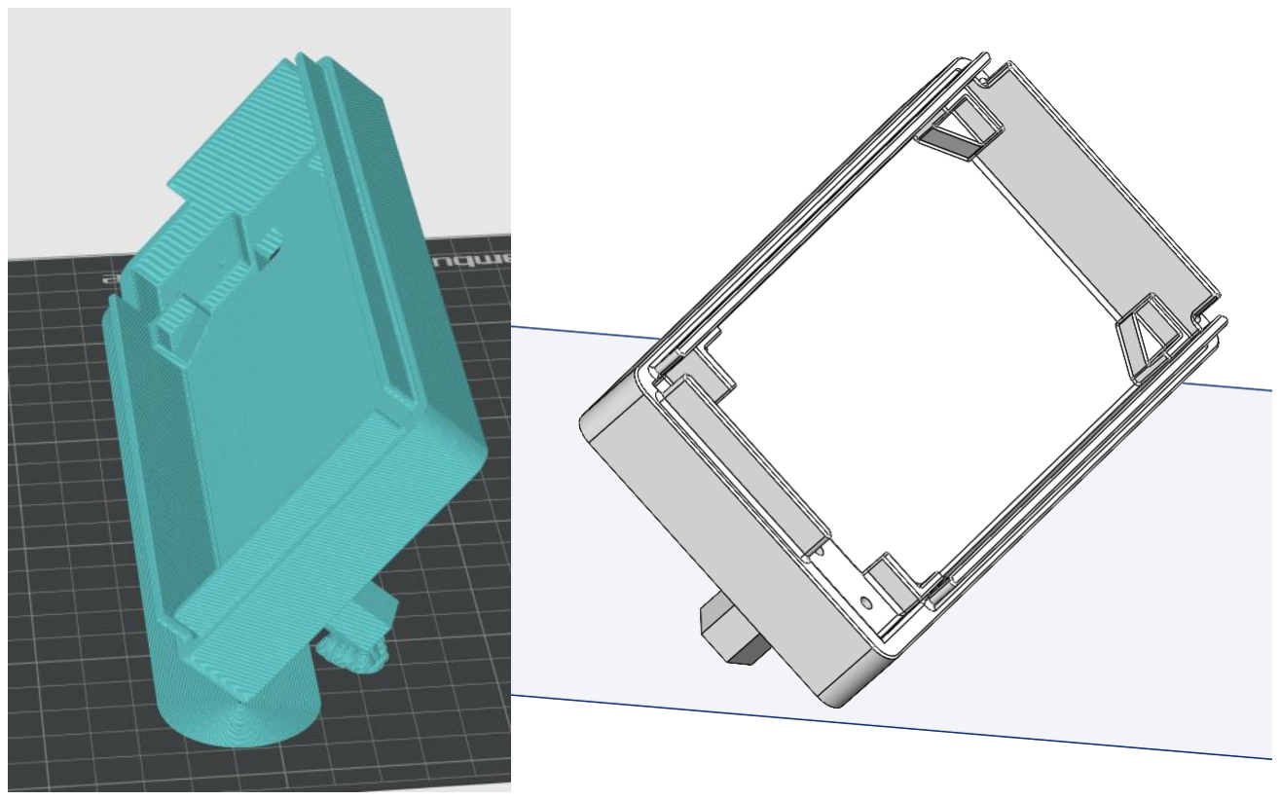
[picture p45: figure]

## 4. Electrical Box Lid

file Name: electricalBoxLid.STL Link: electricalBoxLid (https://drive.google.com/file/d/19DKldQlGTCPF3rQsa5xDPbu3Z4AbDymF/view?usp=drive_link)
Infill: 18%
Color: White
Precision (Flowrate): Low (Fast) Material: PETG
Quantity: 1

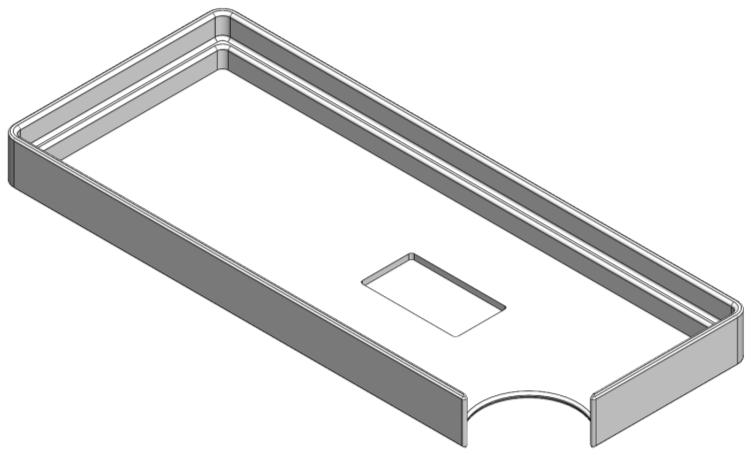
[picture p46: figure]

## 5. Knob

file Name: knob.STL
Link: knob (https://drive.google.com/file/d/1crN5UoaUlNa2Llj3XZiAWvWRgmY0Fkia/view?usp=drive_link)
Infill: 15%
Wall Loops: 5
Sparse infill Pattern: 3D honeycomb Color: White
Precision (Flowrate): Medium (Medium) Material: PETG
Quantity: 1

## 6. Fastner4x

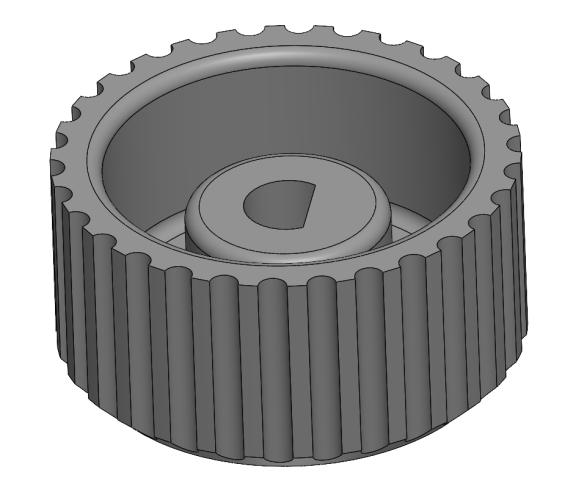
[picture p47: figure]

file Name: fastner4x.STL
Link: fastner4x (https://drive.google.com/file/d/1ATYxqI4tpu13BzVuJtUROJL_5joBhkrt/view?usp=drive_link)
Infill: 18%
Color: White
Precision (Flowrate): Low (Fast) Material: PETG
Quantity: 1

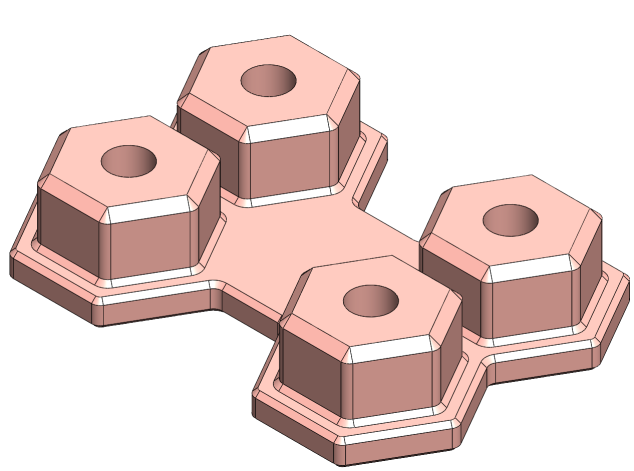
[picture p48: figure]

## 7. Mount Stand

file Name: mountStand.STL
Link: mountStand (https://drive.google.com/file/d/11UVstpQsalSG6O2w7cc4JoI6irmdolFW/view?usp=drive_link)
Infill: 18%
Color: White
Precision (Flowrate): Low(Fast) Material: PETG
Quantity: 1

## 8. Spool

file Name: Spool.STL
Link: Spool (https://drive.google.com/file/d/14eT0i1nj56EyRlMlns6cqcSZ07kcqygc/view?usp=drive_link)
Infill: 15%
Wall Loops: 5

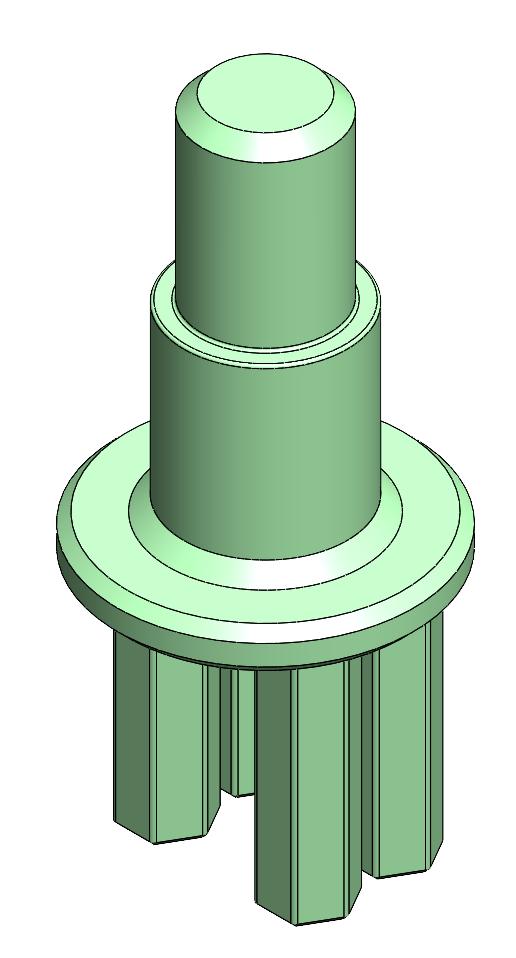
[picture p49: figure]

Sparse infill Pattern: 3D honeycomb Color: White
Precision (Flowrate): Medium (Medium) Material: PETG
Quantity: 1

## 9. Spool Plate

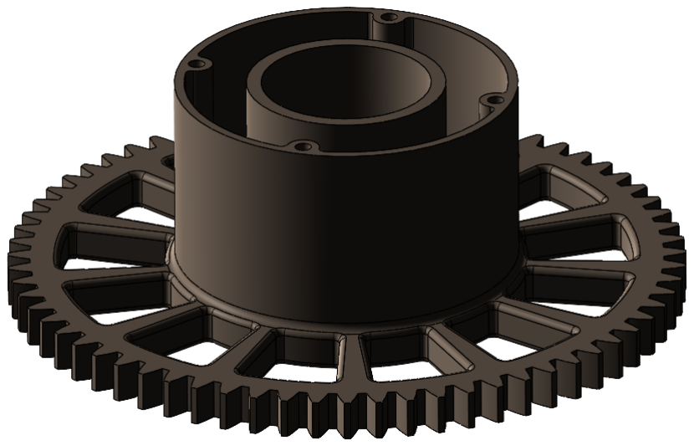
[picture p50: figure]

file Name: spoolPlate.STL
Link: spoolPlate (https://drive.google.com/file/d/1BxrMWAnJaGbtaUbNvoJVXeaaXqdHnRDJ/view?usp=drive_link)
Infill: 18%
Color: White
Precision (Flowrate): Low (Fast) Material: PETG
Quantity: 1

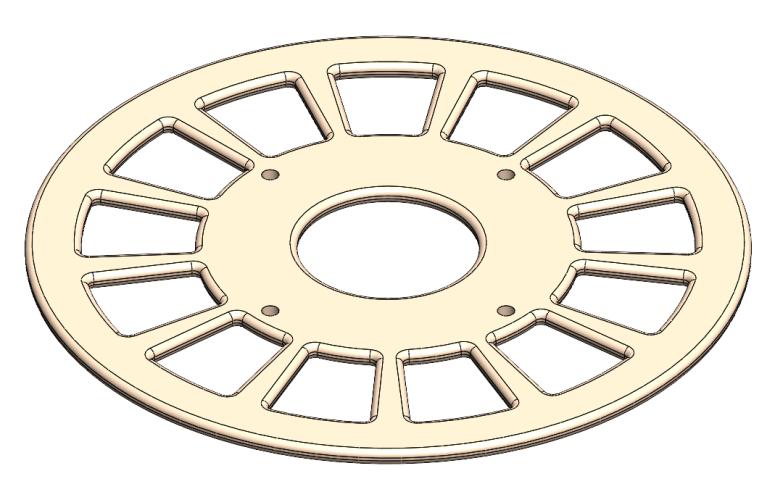
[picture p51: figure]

## 10. Spur Gear

file Name: spurGear.STL
Link: spurGear (https://drive.google.com/file/d/19QPvdigiYyP6yyuL8AWJ5Ni2x9vyFnvE/view?usp=drive_link)
Infill: 15%
Wall Loops: 5
Sparse infill Pattern: 3D honeycomb Color: White
Precision (Flowrate): Medium (Medium) Material: PETG
Quantity: 1

## 11. Fastner

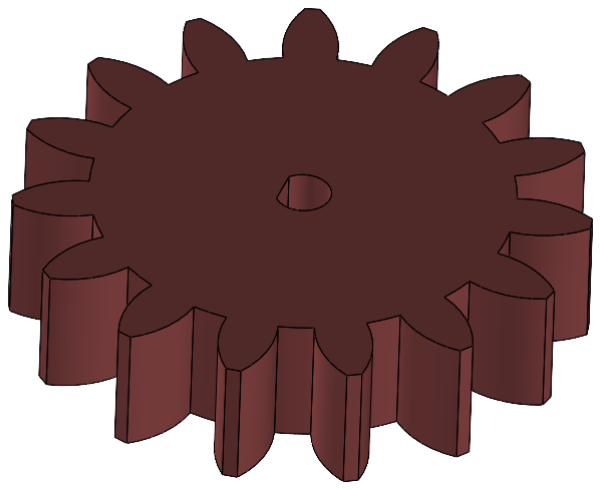
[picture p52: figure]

file Name: fastner_1.STL
Link: fastner_1 (https://drive.google.com/file/d/1ac-slHnMCB7YJgYUPBGSfMUJDFspP_cW/view?usp=drive_link)
Infill: 18%
Color: White
Precision (Flowrate): High (Low) Material: PETG
Quantity: 2

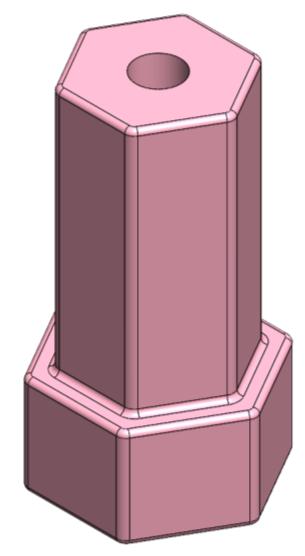
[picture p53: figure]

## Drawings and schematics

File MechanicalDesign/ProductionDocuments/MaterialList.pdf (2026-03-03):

# Bolts:

M4

40mm = 16 + 5 = 21
20mm = 16 + 5 = 21

M3

10mm = 2 + 5 = 7

# Bearing:

# Model: 63005-2RS1 Chinese version

Bore diameter: | 25mm
Outer Diameter: | 47mm
Width: | 16mm

# Wooden Parts:

# 1. Block (Drawing sheet added) 2. Rod (Drawing sheet added)

1

2

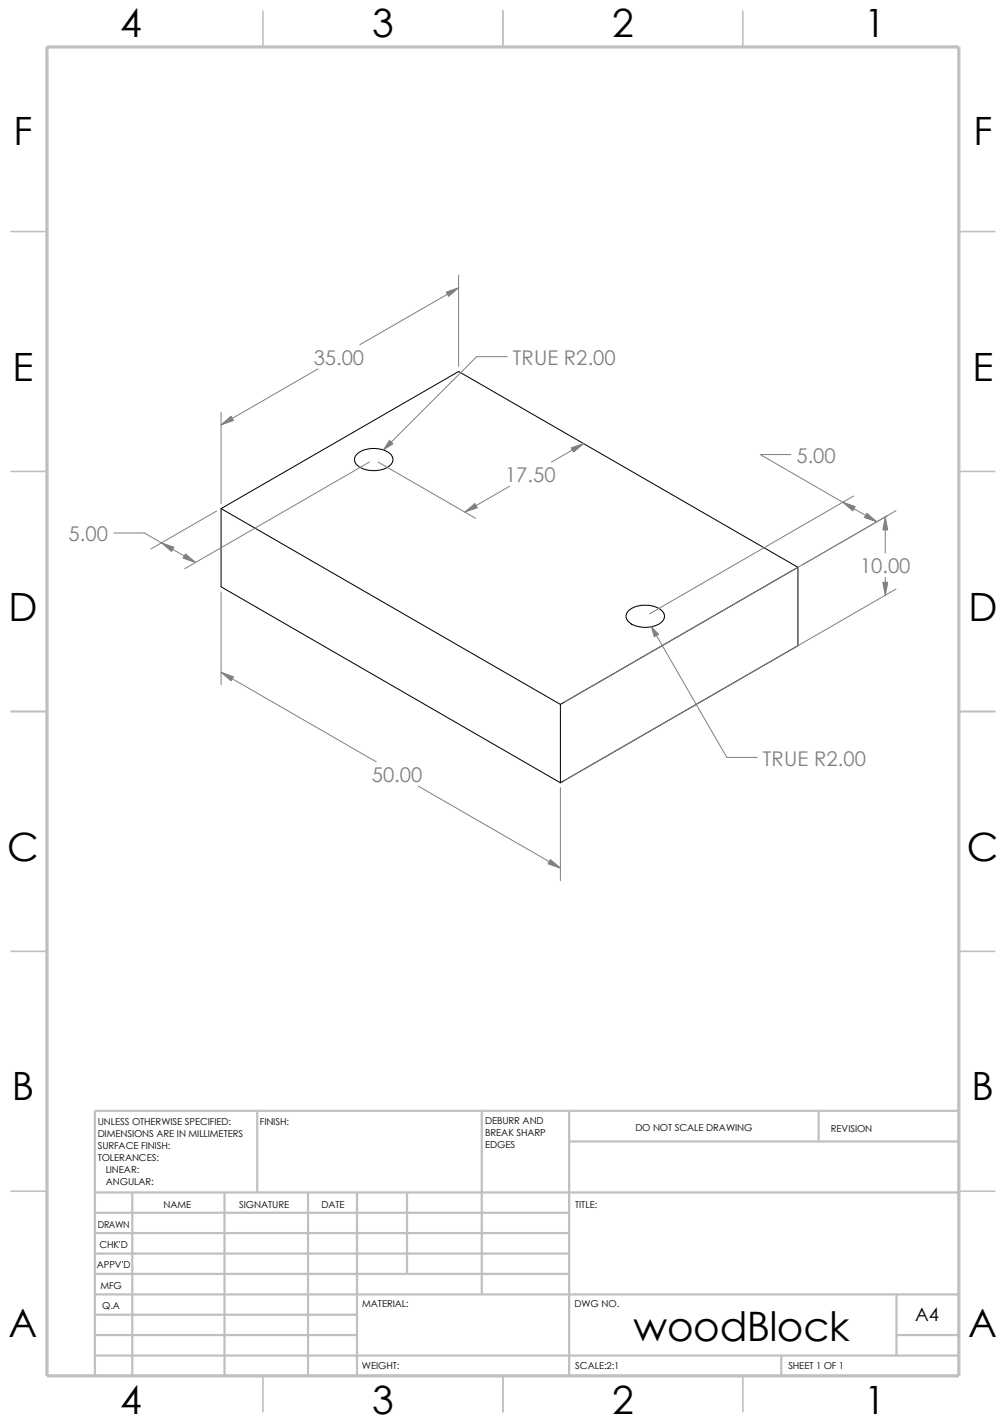
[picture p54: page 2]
FINISH:; EDGES; DO NOT SCALE DRAWING; REVISION; SCALE:2:1; SHEET 1 OF 1; WEIGHT:; DEBURR AND BREAK SHARP; TRUE R2.00

UNLESS OTHERWISE SPECIFIED:
DIMENSIONS ARE IN MILLIMETERS
SURFACE FINISH:
TOLERANCES:
LINEAR:
ANGULAR:

NAME | SIGNATURE | DATE | | | | TITLE:

DRAWN
CHK'D
APPV'D

MFG
Q.A | | | | MATERIAL: | DWG NO. woodBlock | A4

E E

F F

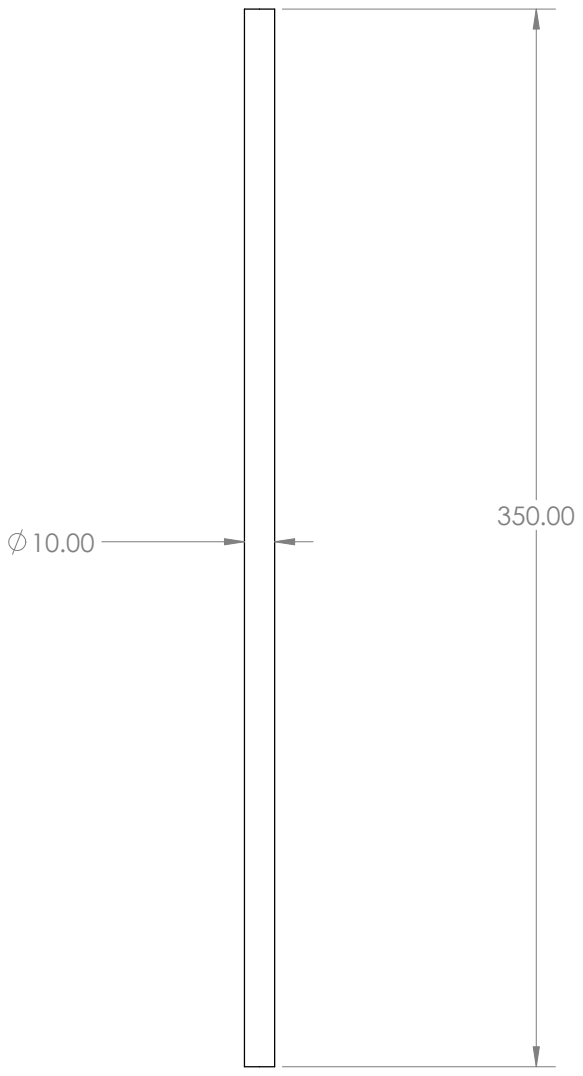
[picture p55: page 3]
SCALE:1:2; SHEET 1 OF 1; WEIGHT:; DO NOT SCALE DRAWING; REVISION; FINISH:; EDGES; DEBURR AND BREAK SHARP

UNLESS OTHERWISE SPECIFIED:
DIMENSIONS ARE IN MILLIMETERS
SURFACE FINISH:
TOLERANCES:
LINEAR:
ANGULAR:

NAME | SIGNATURE | DATE | | | | TITLE:

DRAWN
CHK'D
APPV'D

MFG
Q.A | | | | MATERIAL: | DWG NO. metalRod | A4

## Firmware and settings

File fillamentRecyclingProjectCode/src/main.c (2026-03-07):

#include <stdio.h>
#include <string.h>
#include "freertos/FreeRTOS.h"
#include "freertos/task.h"
#include "driver/i2c.h"
#include "driver/gpio.h"
#include "driver/spi_master.h"
#include "esp_log.h"
#include "esp_timer.h"
#include "nvs_flash.h"
#include "nvs.h"

#include "sh1106.h"
#include "AiEsp32RotaryEncoder.h"

static const char *TAG = "MAIN";

// Pin definitions for ESP32-C6 (fixed pins)
#define I2C_MASTER_SCL_IO       20
#define I2C_MASTER_SDA_IO       19
#define I2C_MASTER_NUM          I2C_NUM_0
#define I2C_MASTER_FREQ_HZ      400000

#define ROTARY_ENCODER_A_PIN    15
#define ROTARY_ENCODER_B_PIN    18
#define ROTARY_ENCODER_BUTTON_PIN 14
#define ROTARY_ENCODER_VCC_PIN  -1
#define ROTARY_ENCODER_STEPS    2  // 2 pulses per detent click

// Configurable pin defaults
#define DEFAULT_STEPPER_STEP_PIN    4
#define DEFAULT_STEPPER_DIR_PIN     5
#define DEFAULT_STEPPER_ENABLE_PIN  6
#define DEFAULT_HEATER_PIN          7
#define DEFAULT_MAX6675_CLK_PIN     10
#define DEFAULT_MAX6675_CS_PIN      11
#define DEFAULT_MAX6675_DO_PIN      12

#define SCREEN_ADDRESS          0x3C

// Configurable pins (loaded from NVS)
static int pin_stepper_step = DEFAULT_STEPPER_STEP_PIN;
static int pin_stepper_dir = DEFAULT_STEPPER_DIR_PIN;
static int pin_stepper_enable = DEFAULT_STEPPER_ENABLE_PIN;
static int pin_heater = DEFAULT_HEATER_PIN;
static int pin_max6675_clk = DEFAULT_MAX6675_CLK_PIN;
static int pin_max6675_cs = DEFAULT_MAX6675_CS_PIN;
static int pin_max6675_do = DEFAULT_MAX6675_DO_PIN;

// Display and encoder instances
static sh1106_t display;
static AiEsp32RotaryEncoder rotaryEncoder;

// Menu state machine
typedef enum {
    SPLASH,
    MAIN_MENU,
    START_RUNNING,
    START_CONFIRM_STOP,
    TEMP_SET,
    MOTOR_SPEED_SET,
    MICROSTEP_SET,
    PID_MENU,
    KP_SET,
    KI_SET,
    KD_SET,
    PIN_MENU,
    PIN_STEP_SET,
    PIN_DIR_SET,
    PIN_ENABLE_SET,
    PIN_HEATER_SET,
    PIN_MAX6675_CLK_SET,
    PIN_MAX6675_CS_SET,
    PIN_MAX6675_DO_SET,
    HOTEND_MODE_MENU,
    OPEN_LOOP_POWER_SET
} menu_state_t;

static menu_state_t current_state = SPLASH;

// Menu variables
static int main_menu_index = 0;
static int start_menu_index = 0;
static int confirm_stop_index = 1;
static int pid_menu_index = 0;
static int pin_menu_index = 0;
static int temperature = 180;  // Default to common PLA temp
static int motor_speed = 50;   // Stepper motor speed (0-100%)
static int microstep = 16;     // Microstep setting (1, 2, 4, 8, 16, 32)
static uint32_t splash_start_time = 0;
static bool needs_update = true;
static int32_t last_encoder_value = 0;
static bool is_running = false;  // Track if process is running
static uint32_t run_start_time = 0;  // Track run time

// Hotend mode: 0=Closed Loop (PID), 1=Open Loop (fixed power)
static int hotend_mode = 0;
static int open_loop_power = 50;  // Open loop heater power (0-100%)
static int hotend_mode_menu_index = 0;
static menu_state_t confirm_return_state = START_RUNNING;  // Where to return on cancel

// Long press detection
static bool last_raw_btn_state = false;
static uint32_t btn_debounce_time_ms = 0;
static bool debounced_btn_state = false;
static uint32_t btn_press_start_time = 0;
static bool long_press_fired = false;
#define LONG_PRESS_DURATION_MS 1000

// Stepper motor control via hardware timer (precise pulse generation)
static esp_timer_handle_t stepper_timer_handle = NULL;
static uint32_t current_stepper_interval_us = 0;
static bool heater_enabled = false;

static void stepper_timer_start(void);
static void stepper_timer_stop(void);

// Heater time-proportional control state
static uint32_t heater_window_start = 0;
#define HEATER_WINDOW_MS 1000  // 1-second window for time-proportional control

// Animation frame counter
static uint8_t anim_frame = 0;
static uint32_t last_anim_time = 0;

// For slow/fast rotation detection on sliders
static uint32_t last_temp_change_time = 0;
static int32_t temp_encoder_base = 0;  // Base encoder value for temperature

// PID Controller for temperature
static float current_temp = 25.0f;     // Current temperature from MAX6675
static float target_temp = 180.0f;     // Set temperature
static float pid_output = 0.0f;        // PID output (0-100%)
static uint32_t last_max6675_read = 0; // Last MAX6675 read time

// PID constants (stored as int x10 for display, converted to float for calculation)
static int kp_x10 = 20;    // Kp = 2.0
static int ki_x10 = 1;     // Ki = 0.1
static int kd_x10 = 10;    // Kd = 1.0

// PID state variables
static float pid_integral = 0.0f;
static float pid_last_error = 0.0f;
static uint32_t last_pid_time = 0;

// NVS handle
static nvs_handle_t nvs_handle_settings;

// Icon bitmap (24x24) - Recycling symbol
static const uint8_t icon_bmp[] = {
    0x00, 0x3C, 0x00, 0x00, 0x7E, 0x00, 0x01, 0xFF, 0x80, 0x03, 0xC3, 0xC0,
    0x03, 0x81, 0xC0, 0x07, 0x00, 0xE0, 0x1E, 0x00, 0x78, 0x3C, 0x18, 0x3C,
    0x38, 0x3C, 0x1C, 0x30, 0x7E, 0x0C, 0x30, 0xFF, 0x0C, 0x30, 0xFF, 0x0C,
    0x38, 0x3C, 0x1C, 0x3C, 0x18, 0x3C, 0x1E, 0x00, 0x78, 0x07, 0x00, 0xE0,
    0x03, 0x81, 0xC0, 0x03, 0xC3, 0xC0, 0x01, 0xFF, 0x80, 0x00, 0x7E, 0x00,
    0x00, 0x3C, 0x00, 0x00, 0x00, 0x00, 0x00, 0x00, 0x00, 0x00, 0x00, 0x00
};

// Small icons (8x8)
static const uint8_t icon_temp[] = {  // Thermometer
    0x18, 0x24, 0x24, 0x24, 0x24, 0x5A, 0x7E, 0x3C
};
static const uint8_t icon_fan[] = {   // Fan
    0x18, 0x3C, 0x7E, 0xE7, 0xE7, 0x7E, 0x3C, 0x18
};
static const uint8_t icon_play[] = {  // Play arrow
    0x00, 0x60, 0x78, 0x7E, 0x7E, 0x78, 0x60, 0x00
};
static const uint8_t icon_stop[] = {  // Stop square
    0x00, 0x7E, 0x7E, 0x7E, 0x7E, 0x7E, 0x7E, 0x00
};
static const uint8_t icon_back[] = {  // Back arrow
    0x10, 0x30, 0x7E, 0xFF, 0x7E, 0x30, 0x10, 0x00
};
static const uint8_t icon_motor[] = {  // Motor/stepper
    0x3C, 0x42, 0x99, 0xBD, 0xBD, 0x99, 0x42, 0x3C
};
static const uint8_t icon_gear[] = {   // Gear/settings
    0x18, 0x5A, 0xFF, 0xDB, 0xDB, 0xFF, 0x5A, 0x18
};

// Helper function to map value from one range to another
static int map_value(int x, int in_min, int in_max, int out_min, int out_max) {
    return (x - in_min) * (out_max - out_min) / (in_max - in_min) + out_min;
}

// PID Controller calculation (derivative-on-measurement to avoid setpoint kick)
static void update_pid(uint32_t now_ms) {
    float dt = (now_ms - last_pid_time) / 1000.0f;  // Convert to seconds
    
    if (dt < 0.01f) return;  // Don't update too frequently
    
    // Convert stored int values to float
    float Kp = kp_x10 / 10.0f;
    float Ki = ki_x10 / 10.0f;
    float Kd = kd_x10 / 10.0f;
    
    target_temp = (float)temperature;
    float error = target_temp - current_temp;
    
    // Proportional term
    float p_term = Kp * error;
    
    // Integral term with anti-windup
    pid_integral += error * dt;
    if (pid_integral > 100.0f) pid_integral = 100.0f;
    if (pid_integral < -100.0f) pid_integral = -100.0f;
    float i_term = Ki * pid_integral;
    
    // Derivative term (on measurement, not error, to avoid setpoint kick)
    float d_measurement = -(current_temp - pid_last_error) / dt;
    float d_term = Kd * d_measurement;
    
    // Calculate output
    pid_output = p_term + i_term + d_term;
    
    // Clamp output to 0-100%
    if (pid_output > 100.0f) pid_output = 100.0f;
    if (pid_output < 0.0f) pid_output = 0.0f;
    
    // Store current measurement for next derivative calculation
    pid_last_error = current_temp;
    last_pid_time = now_ms;
}

// Helper: write an NVS int32 only if the value differs from what's stored (reduces flash wear)
static void nvs_set_i32_if_changed(nvs_handle_t handle, const char *key, int32_t value) {
    int32_t stored;
    if (nvs_get_i32(handle, key, &stored) != ESP_OK || stored != value) {
        nvs_set_i32(handle, key, value);
    }
}

// Save settings to NVS flash
static void save_settings_to_nvs(void) {
    nvs_set_i32_if_changed(nvs_handle_settings, "temperature", temperature);
    nvs_set_i32_if_changed(nvs_handle_settings, "motor_speed", motor_speed);
    nvs_set_i32_if_changed(nvs_handle_settings, "microstep", microstep);
    nvs_set_i32_if_changed(nvs_handle_settings, "kp_x10", kp_x10);
    nvs_set_i32_if_changed(nvs_handle_settings, "ki_x10", ki_x10);
    nvs_set_i32_if_changed(nvs_handle_settings, "kd_x10", kd_x10);
    nvs_set_i32_if_changed(nvs_handle_settings, "hotend_mode", hotend_mode);
    nvs_set_i32_if_changed(nvs_handle_settings, "ol_power", open_loop_power);
    // Save pin configurations
    nvs_set_i32_if_changed(nvs_handle_settings, "pin_step", pin_stepper_step);
    nvs_set_i32_if_changed(nvs_handle_settings, "pin_dir", pin_stepper_dir);
    nvs_set_i32_if_changed(nvs_handle_settings, "pin_enable", pin_stepper_enable);
    nvs_set_i32_if_changed(nvs_handle_settings, "pin_heater", pin_heater);
    nvs_set_i32_if_changed(nvs_handle_settings, "pin_clk", pin_max6675_clk);
    nvs_set_i32_if_changed(nvs_handle_settings, "pin_cs", pin_max6675_cs);
    nvs_set_i32_if_changed(nvs_handle_settings, "pin_do", pin_max6675_do);
    nvs_commit(nvs_handle_settings);
    ESP_LOGI(TAG, "Settings saved to flash");
}

// Load settings from NVS flash
static void load_settings_from_nvs(void) {
    int32_t val;
    if (nvs_get_i32(nvs_handle_settings, "temperature", &val) == ESP_OK) {
        temperature = val;
    }
    if (nvs_get_i32(nvs_handle_settings, "motor_speed", &val) == ESP_OK) {
        motor_speed = val;
    }
    if (nvs_get_i32(nvs_handle_settings, "microstep", &val) == ESP_OK) {
        microstep = val;
    }
    if (nvs_get_i32(nvs_handle_settings, "kp_x10", &val) == ESP_OK) {
        kp_x10 = val;
    }
    if (nvs_get_i32(nvs_handle_settings, "ki_x10", &val) == ESP_OK) {
        ki_x10 = val;
    }
    if (nvs_get_i32(nvs_handle_settings, "kd_x10", &val) == ESP_OK) {
        kd_x10 = val;
    }
    if (nvs_get_i32(nvs_handle_settings, "hotend_mode", &val) == ESP_OK) {
        hotend_mode = val;
    }
    if (nvs_get_i32(nvs_handle_settings, "ol_power", &val) == ESP_OK) {
        open_loop_power = val;
    }
    // Load pin configurations
    if (nvs_get_i32(nvs_handle_settings, "pin_step", &val) == ESP_OK) {
        pin_stepper_step = val;
    }
    if (nvs_get_i32(nvs_handle_settings, "pin_dir", &val) == ESP_OK) {
        pin_stepper_dir = val;
    }
    if (nvs_get_i32(nvs_handle_settings, "pin_enable", &val) == ESP_OK) {
        pin_stepper_enable = val;
    }
    if (nvs_get_i32(nvs_handle_settings, "pin_heater", &val) == ESP_OK) {
        pin_heater = val;
    }
    if (nvs_get_i32(nvs_handle_settings, "pin_clk", &val) == ESP_OK) {
        pin_max6675_clk = val;
    }
    if (nvs_get_i32(nvs_handle_settings, "pin_cs", &val) == ESP_OK) {
        pin_max6675_cs = val;
    }
    if (nvs_get_i32(nvs_handle_settings, "pin_do", &val) == ESP_OK) {
        pin_max6675_do = val;
    }
    ESP_LOGI(TAG, "Settings loaded: Temp=%d, Speed=%d, Microstep=%d",
             temperature, motor_speed, microstep);
}

// Read temperature from MAX6675 (bit-banged SPI)
static float read_max6675_temperature(void) {
    uint16_t data = 0;
    
    // Ensure CLK is LOW before starting (MAX6675 requires SCK LOW when not in use)
    gpio_set_level(pin_max6675_clk, 0);
    
    // Pull CS low to start communication - D15 appears on SO immediately
    gpio_set_level(pin_max6675_cs, 0);
    esp_rom_delay_us(10);
    
    // Read 16 bits MSB first
    // Data is available on SO after CS goes LOW (for D15) and after each falling edge
    for (int i = 15; i >= 0; i--) {
        // Read current bit (data is already valid on SO)
        if (gpio_get_level(pin_max6675_do)) {
            data |= (1 << i);
        }
        
        // Clock pulse: HIGH then LOW shifts next bit onto SO
        gpio_set_level(pin_max6675_clk, 1);
        esp_rom_delay_us(10);
        gpio_set_level(pin_max6675_clk, 0);
        esp_rom_delay_us(10);
    }
    
    // Pull CS high to end communication and start new conversion
    // CLK remains LOW (required during conversion)
    gpio_set_level(pin_max6675_cs, 1);
    
    // Check for thermocouple open circuit (bit 2)
    if (data & 0x04) {
        ESP_LOGW(TAG, "MAX6675: Thermocouple not connected!");
        return -1.0f;  // Error indicator
    }
    
    // Extract temperature (bits 14:3), each bit = 0.25°C
    data >>= 3;
    float temp = data * 0.25f;
    
    return temp;
}

// Initialize MAX6675 pins
static void init_max6675(void) {
    // Configure CLK and CS as outputs
    gpio_config_t out_conf = {
        .pin_bit_mask = (1ULL << pin_max6675_clk) | (1ULL << pin_max6675_cs),
        .mode = GPIO_MODE_OUTPUT,
        .pull_up_en = GPIO_PULLUP_DISABLE,
        .pull_down_en = GPIO_PULLDOWN_DISABLE,
        .intr_type = GPIO_INTR_DISABLE,
    };
    gpio_config(&out_conf);
    
    // Configure DO as input
    gpio_config_t in_conf = {
        .pin_bit_mask = (1ULL << pin_max6675_do),
        .mode = GPIO_MODE_INPUT,
        .pull_up_en = GPIO_PULLUP_ENABLE,
        .pull_down_en = GPIO_PULLDOWN_DISABLE,
        .intr_type = GPIO_INTR_DISABLE,
    };
    gpio_config(&in_conf);
    
    // Set initial states
    gpio_set_level(pin_max6675_cs, 1);  // CS high (inactive)
    gpio_set_level(pin_max6675_clk, 0); // CLK low (must be LOW when idle per MAX6675 datasheet)
    
    ESP_LOGI(TAG, "MAX6675 initialized: CLK=%d, CS=%d, DO=%d", 
             pin_max6675_clk, pin_max6675_cs, pin_max6675_do);
}

// Initialize hardware control pins
static void init_hardware_control(void) {
    // Configure stepper motor pins
    gpio_config_t stepper_conf = {
        .pin_bit_mask = (1ULL << pin_stepper_step) | (1ULL << pin_stepper_dir) | (1ULL << pin_stepper_enable),
        .mode = GPIO_MODE_OUTPUT,
        .pull_up_en = GPIO_PULLUP_DISABLE,
        .pull_down_en = GPIO_PULLDOWN_DISABLE,
        .intr_type = GPIO_INTR_DISABLE,
    };
    gpio_config(&stepper_conf);
    
    // Disable stepper initially (HIGH = disabled for TB6600)
    gpio_set_level(pin_stepper_enable, 1);
    gpio_set_level(pin_stepper_dir, 0);
    gpio_set_level(pin_stepper_step, 0);
    
    // Configure heater pin
    gpio_config_t heater_conf = {
        .pin_bit_mask = (1ULL << pin_heater),
        .mode = GPIO_MODE_OUTPUT,
        .pull_up_en = GPIO_PULLUP_DISABLE,
        .pull_down_en = GPIO_PULLDOWN_DISABLE,
        .intr_type = GPIO_INTR_DISABLE,
    };
    gpio_config(&heater_conf);
    gpio_set_level(pin_heater, 0);  // Heater off initially
    
    ESP_LOGI(TAG, "Hardware pins initialized: STEP=%d, DIR=%d, EN=%d, HEATER=%d", 
             pin_stepper_step, pin_stepper_dir, pin_stepper_enable, pin_heater);
}

// Start the process - enable heater and motor
static void start_process(void) {
    is_running = true;
    uint32_t now_ms = esp_timer_get_time() / 1000;
    run_start_time = now_ms;
    pid_integral = 0.0f;  // Reset PID integral
    pid_last_error = current_temp;  // Initialize to current measurement (derivative-on-measurement)
    last_pid_time = now_ms;
    heater_window_start = now_ms;
    
    // Enable stepper motor (LOW = enabled for TB6600)
    gpio_set_level(pin_stepper_enable, 0);
    gpio_set_level(pin_stepper_dir, 1);  // Set direction
    
    heater_enabled = true;
    stepper_timer_start();  // Start hardware timer for precise step pulses
    ESP_LOGI(TAG, "Process started - Heater and motor enabled");
}

// Stop the process - disable heater and motor
static void stop_process(void) {
    is_running = false;
    heater_enabled = false;
    stepper_timer_stop();  // Stop hardware timer first
    
    // Disable stepper motor (HIGH = disabled for TB6600)
    gpio_set_level(pin_stepper_enable, 1);
    gpio_set_level(pin_stepper_step, 0);
    
    // Turn off heater
    gpio_set_level(pin_heater, 0);
    pid_output = 0.0f;
    
    ESP_LOGI(TAG, "Process stopped - Heater and motor disabled");
}

// Update heater using time-proportional control (software PWM at 1Hz)
// This gives proportional power output without requiring hardware PWM
static void update_heater_output(uint32_t now_ms) {
    if (heater_enabled && is_running) {
        uint32_t elapsed = now_ms - heater_window_start;
        if (elapsed >= HEATER_WINDOW_MS) {
            heater_window_start = now_ms;
            elapsed = 0;
        }
        // pid_output is 0-100%, convert to on-time within window
        uint32_t on_time_ms = (uint32_t)(pid_output * HEATER_WINDOW_MS / 100.0f);
        if (elapsed < on_time_ms) {
            gpio_set_level(pin_heater, 1);
        } else {
            gpio_set_level(pin_heater, 0);
        }
    } else {
        gpio_set_level(pin_heater, 0);
    }
}

// Stepper motor timer callback - runs from high-priority esp_timer task
// Provides precise, jitter-free step pulses independent of main loop timing
static void stepper_timer_callback(void *arg) {
    gpio_set_level(pin_stepper_step, 1);
    esp_rom_delay_us(5);  // 5us pulse width (TB6600 needs min 2.5us)
    gpio_set_level(pin_stepper_step, 0);
}
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
void app_main(void) {
    ESP_LOGI(TAG, "Filament Recycling Project Starting...");

    // Initialize NVS (Non-Volatile Storage)
    esp_err_t ret = nvs_flash_init();
    if (ret == ESP_ERR_NVS_NO_FREE_PAGES || ret == ESP_ERR_NVS_NEW_VERSION_FOUND) {
        ESP_ERROR_CHECK(nvs_flash_erase());
        ret = nvs_flash_init();
    }
    ESP_ERROR_CHECK(ret);
    
    // Open NVS handle
    ret = nvs_open("settings", NVS_READWRITE, &nvs_handle_settings);
    if (ret != ESP_OK) {
        ESP_LOGE(TAG, "Error opening NVS handle");
    } else {
        // Load saved settings
        load_settings_from_nvs();
    }

    // Initialize I2C
    ESP_ERROR_CHECK(i2c_master_init());
    ESP_LOGI(TAG, "I2C initialized");

    // Initialize hardware control (stepper motor, heater)
    init_hardware_control();
    
    // Initialize MAX6675 temperature sensor
    init_max6675();

    // Initialize rotary encoder using AiEsp32RotaryEncoder
    AiEsp32RotaryEncoder_init(&rotaryEncoder, 
                               ROTARY_ENCODER_A_PIN, 
                               ROTARY_ENCODER_B_PIN, 
                               ROTARY_ENCODER_BUTTON_PIN, 
                               ROTARY_ENCODER_VCC_PIN, 
                               ROTARY_ENCODER_STEPS);
    AiEsp32RotaryEncoder_begin(&rotaryEncoder);
    AiEsp32RotaryEncoder_setup(&rotaryEncoder, readEncoderISR);
    AiEsp32RotaryEncoder_setBoundaries(&rotaryEncoder, 0, 4, true);
    AiEsp32RotaryEncoder_setAcceleration(&rotaryEncoder, 0);

    // Create stepper motor timer (precise pulse generation from high-priority task)
    const esp_timer_create_args_t stepper_timer_args = {
        .callback = stepper_timer_callback,
        .name = "stepper"
    };
    ESP_ERROR_CHECK(esp_timer_create(&stepper_timer_args, &stepper_timer_handle));
    ESP_LOGI(TAG, "Stepper timer created");

    // Initialize display
    ret = sh1106_init(&display, I2C_MASTER_NUM, SCREEN_ADDRESS);
    if (ret != ESP_OK) {
        ESP_LOGE(TAG, "SH1106 initialization failed");
        return;
    }

    sh1106_clear(&display);
    current_state = SPLASH;
    splash_start_time = esp_timer_get_time() / 1000;  // Convert to milliseconds

    // Main loop
    while (1) {
        uint32_t current_time = esp_timer_get_time() / 1000;

        // Update animation frame (every 200ms)
        if (current_time - last_anim_time > 200) {
            anim_frame++;
            last_anim_time = current_time;
            if (current_state == START_RUNNING) {
                needs_update = true;  // Force redraw for animation
            }
        }
        
        // Read MAX6675 temperature sensor (every 300ms - sensor needs ~220ms conversion time)
        if (current_time - last_max6675_read > 300) {
            float temp = read_max6675_temperature();
            if (temp >= 0) {  // Valid reading (negative means error)
                current_temp = temp;
            }
            last_max6675_read = current_time;
        }

        // Update heater and motor control when running
        if (is_running) {
            if (hotend_mode == 0) {
                // Closed loop - PID temperature control
                update_pid(current_time);
            } else {
                // Open loop - fixed power output
                pid_output = (float)open_loop_power;
            }
            update_heater_output(current_time);
            // Stepper motor is now driven by hardware timer (stepper_timer_handle)
        }

        if (current_state == SPLASH) {
            sh1106_clear(&display);
            
            // Draw border
            sh1106_draw_rect(&display, 0, 0, 128, 64, SH1106_COLOR_WHITE);
            
            // Draw logo
            sh1106_draw_bitmap(&display, (128 - 24) / 2, 8, icon_bmp, 24, 24, SH1106_COLOR_WHITE);
            
            sh1106_set_text_size(&display, 1);
            sh1106_set_text_color(&display, SH1106_COLOR_WHITE, SH1106_COLOR_BLACK);
            sh1106_set_cursor(&display, 20, 38);
            sh1106_print(&display, "FILAMENT RECYCLER");
            
            // Loading bar animation
            int load_width = ((current_time - splash_start_time) * 100) / 2000;
            if (load_width > 100) load_width = 100;
            sh1106_draw_rect(&display, 14, 52, 100, 6, SH1106_COLOR_WHITE);
            sh1106_fill_rect(&display, 16, 54, (load_width * 96) / 100, 2, SH1106_COLOR_WHITE);
            
            sh1106_display(&display);

            if (current_time - splash_start_time > 2000) {
                current_state = MAIN_MENU;
                configure_encoder_for_menu(0, 6, 0, false);
                needs_update = true;
            }
            vTaskDelay(pdMS_TO_TICKS(20));
            continue;
        }

        // Read encoder value
        int32_t new_encoder_value = AiEsp32RotaryEncoder_readEncoder(&rotaryEncoder);
        if (new_encoder_value != last_encoder_value) {
            last_encoder_value = new_encoder_value;
            needs_update = true;
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

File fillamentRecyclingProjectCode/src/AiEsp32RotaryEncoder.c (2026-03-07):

/**
 * AiEsp32RotaryEncoder - ESP-IDF Port
 * 
 * This is an ESP-IDF compatible port of the AiEsp32RotaryEncoder library
 * by Igor Antolic (igorantolic/ai-esp32-rotary-encoder)
 * 
 * Original library: https://github.com/igorantolic/ai-esp32-rotary-encoder
 * License: MIT
 */

#include "AiEsp32RotaryEncoder.h"
#include "freertos/FreeRTOS.h"
#include "freertos/task.h"
#include "esp_log.h"
#include <string.h>

static const char *TAG = "RotaryEncoder";

// Encoder lookup table for quadrature decoding - Full step decoding for reliability
// This table provides better noise immunity
static const int8_t enc_states[] = {0, -1, 1, 0, 1, 0, 0, -1, -1, 0, 0, 1, 0, 1, -1, 0};

// Alternative half-step lookup table for more sensitive detection
// Mark as unused to avoid compile warnings when not referenced
static const int8_t enc_states_half[] __attribute__((unused)) = {
    0,  1, -1,  0,
   -1,  0,  0,  1,
    1,  0,  0, -1,
    0, -1,  1,  0
};

// Global pointer to encoder for ISR (supports single encoder instance)
static AiEsp32RotaryEncoder *g_encoder_instance = NULL;

// Get current time in milliseconds
static inline uint32_t millis(void) {
    return (uint32_t)(esp_timer_get_time() / 1000);
}

// ISR handler wrapper
static void IRAM_ATTR gpio_isr_handler(void *arg) {
    AiEsp32RotaryEncoder *encoder = (AiEsp32RotaryEncoder *)arg;
    if (encoder != NULL) {
        AiEsp32RotaryEncoder_readEncoder_ISR(encoder);
    }
}

void AiEsp32RotaryEncoder_init(AiEsp32RotaryEncoder *encoder,
                                gpio_num_t encoder_a_pin,
                                gpio_num_t encoder_b_pin,
                                gpio_num_t encoder_button_pin,
                                gpio_num_t encoder_vcc_pin,
                                uint8_t encoder_steps) {
    memset(encoder, 0, sizeof(AiEsp32RotaryEncoder));
    
    encoder->encoder_a_pin = encoder_a_pin;
    encoder->encoder_b_pin = encoder_b_pin;
    encoder->encoder_button_pin = encoder_button_pin;
    encoder->encoder_vcc_pin = encoder_vcc_pin;
    encoder->encoder_steps = encoder_steps;
    
    encoder->_minEncoderValue = -2147483648LL;
    encoder->_maxEncoderValue = 2147483647LL;
    encoder->circleValues = false;
    encoder->_acceleration = 0;
    encoder->_pauseLength = 200;
    encoder->_fastRotationLimit = 60;
    
    encoder->old_AB = 0;
    encoder->encoder_position = 0;
    encoder->last_read_encoder_position = 0;
    
    encoder->_buttonState = BUT_UP;
    encoder->_isButtonPulldown = false;
    encoder->_buttonDisabled = false;
    
    g_encoder_instance = encoder;
}

void AiEsp32RotaryEncoder_initButtonPulldown(AiEsp32RotaryEncoder *encoder,
                                              gpio_num_t encoder_a_pin,
                                              gpio_num_t encoder_b_pin,
                                              gpio_num_t encoder_button_pin,
                                              gpio_num_t encoder_vcc_pin,
                                              uint8_t encoder_steps) {
    AiEsp32RotaryEncoder_init(encoder, encoder_a_pin, encoder_b_pin, 
                               encoder_button_pin, encoder_vcc_pin, encoder_steps);
    encoder->_isButtonPulldown = true;
}

void AiEsp32RotaryEncoder_begin(AiEsp32RotaryEncoder *encoder) {
    // Configure encoder pins with internal pull-ups
    gpio_config_t io_conf_encoder = {
        .intr_type = GPIO_INTR_ANYEDGE,
        .mode = GPIO_MODE_INPUT,
        .pin_bit_mask = (1ULL << encoder->encoder_a_pin) | (1ULL << encoder->encoder_b_pin),
        .pull_down_en = GPIO_PULLDOWN_DISABLE,
        .pull_up_en = GPIO_PULLUP_ENABLE,
    };
    gpio_config(&io_conf_encoder);
    
    // Configure button pin
    if (encoder->encoder_button_pin >= 0) {
        gpio_config_t io_conf_button = {
            .intr_type = GPIO_INTR_DISABLE,
            .mode = GPIO_MODE_INPUT,
            .pin_bit_mask = (1ULL << encoder->encoder_button_pin),
            .pull_down_en = encoder->_isButtonPulldown ? GPIO_PULLDOWN_ENABLE : GPIO_PULLDOWN_DISABLE,
            .pull_up_en = encoder->_isButtonPulldown ? GPIO_PULLUP_DISABLE : GPIO_PULLUP_ENABLE,
        };
        gpio_config(&io_conf_button);
    }
    
    // Configure VCC pin if used
    if (encoder->encoder_vcc_pin >= 0) {
        gpio_config_t io_conf_vcc = {
            .intr_type = GPIO_INTR_DISABLE,
            .mode = GPIO_MODE_OUTPUT,
            .pin_bit_mask = (1ULL << encoder->encoder_vcc_pin),
            .pull_down_en = GPIO_PULLDOWN_DISABLE,
            .pull_up_en = GPIO_PULLUP_DISABLE,
        };
        gpio_config(&io_conf_vcc);
        gpio_set_level(encoder->encoder_vcc_pin, 1);
    }
    
    // Read initial state
    encoder->old_AB = 0;
    if (gpio_get_level(encoder->encoder_a_pin)) encoder->old_AB |= (1 << 0);
    if (gpio_get_level(encoder->encoder_b_pin)) encoder->old_AB |= (1 << 1);
    
    ESP_LOGI(TAG, "Rotary encoder initialized - A:%d B:%d BTN:%d", 
             encoder->encoder_a_pin, encoder->encoder_b_pin, encoder->encoder_button_pin);
}

void AiEsp32RotaryEncoder_setup(AiEsp32RotaryEncoder *encoder, void (*isr_callback)(void)) {
    (void)isr_callback; // Not used in this implementation
    
    // Install GPIO ISR service if not already installed
    gpio_install_isr_service(0);
    
    // Add ISR handlers for encoder pins
    gpio_isr_handler_add(encoder->encoder_a_pin, gpio_isr_handler, encoder);
    gpio_isr_handler_add(encoder->encoder_b_pin, gpio_isr_handler, encoder);
    
    ESP_LOGI(TAG, "Rotary encoder ISR setup complete");
}
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

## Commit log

2026-02-23 Optimzed and fixed several issues
    [main.c]
2026-03-02 Fixed stepper motor
2026-03-03 Added the mechanical desing
    [15xSpurGear.SLDPRT, 17xSpurGear.SLDPRT, 6008.SLDASM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]
2026-03-07 Added rendered images
    [MotordriverAssebly.SLDASM, mainBody.SLDPRT]
